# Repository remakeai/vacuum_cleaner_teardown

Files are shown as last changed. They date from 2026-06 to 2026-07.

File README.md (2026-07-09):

# vacuum_cleaner_teardown
A home vacuum robot cleaner teardown

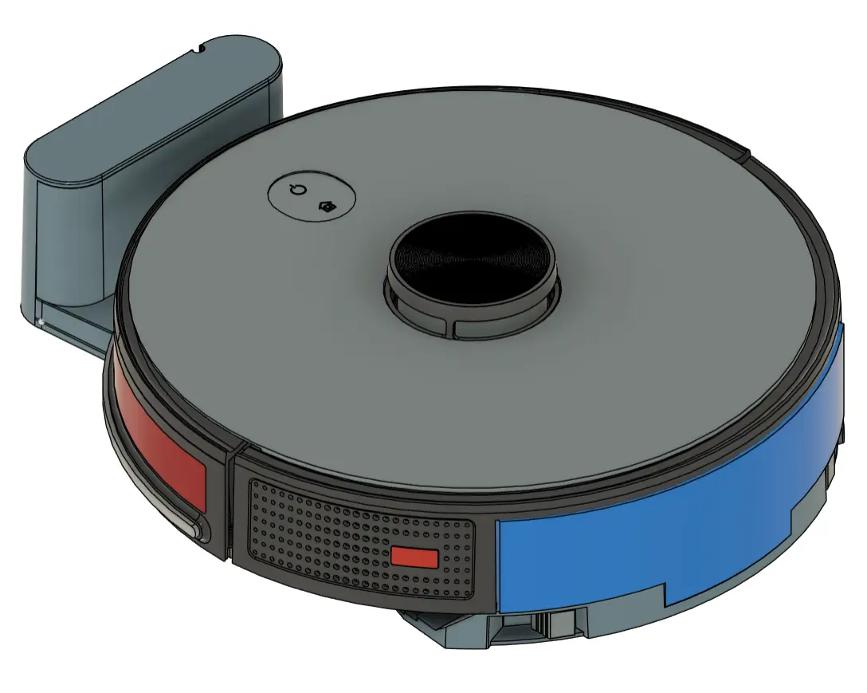
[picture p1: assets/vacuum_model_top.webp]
Vacuum cleaner 3D model top view


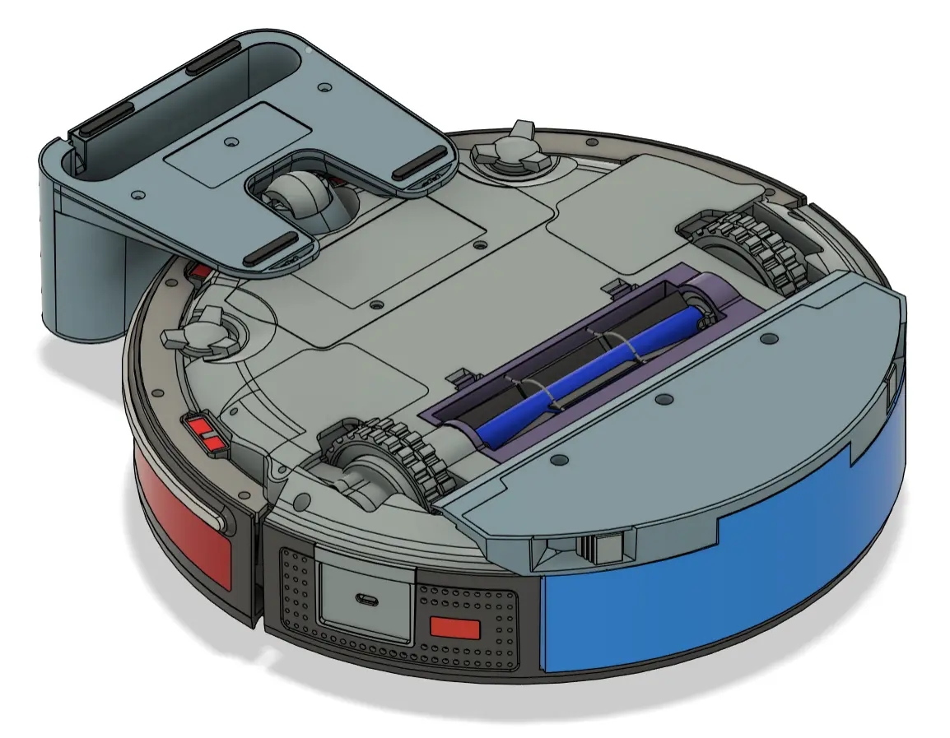
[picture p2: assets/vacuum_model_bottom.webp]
Vacuum cleaner 3D model bottom view


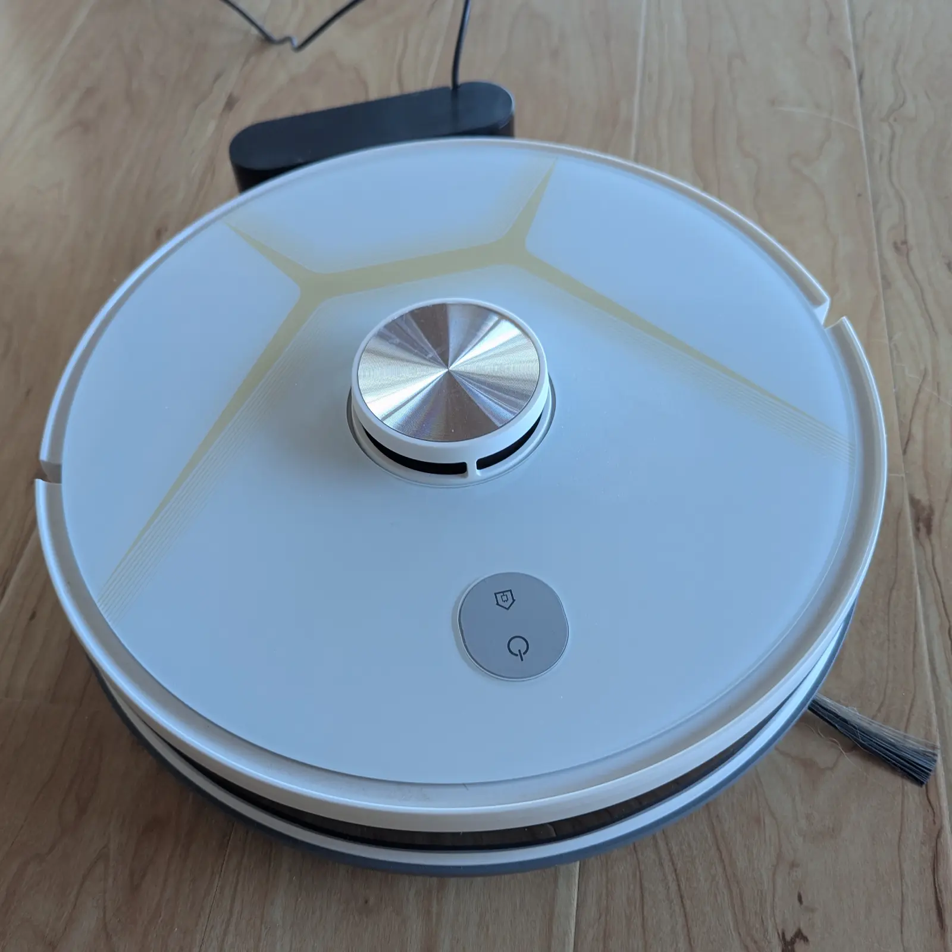
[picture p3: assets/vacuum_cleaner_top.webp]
Vacuum cleaner photo


## PCB

| Device | Model |
| --- | --- |
| Allwinner F1C200s | 64MB in-package RAM |
| BoyaMicro 25Q128ESS1G |  |
| Wheel motor driver | A4950T |
| Wheel motor | 365SA1887 DC 7.4V w/encoder |
| Battery | 3S 2600mAh |
| MCU | Artery AT32F403AVGT7 |
| WiFi | SV6355 2.4GHz WiFi BLE 5.0 module |
| Side brush motors | RF-500C-13430 DV 7.4V |
| Suction fan | EBO Innovation EBO-A65126 DC 8.4V 1.4A, DC 12.6V 2.2A |
| Speaker | 8 Ohm |
| Audio amp | 8002D1 |

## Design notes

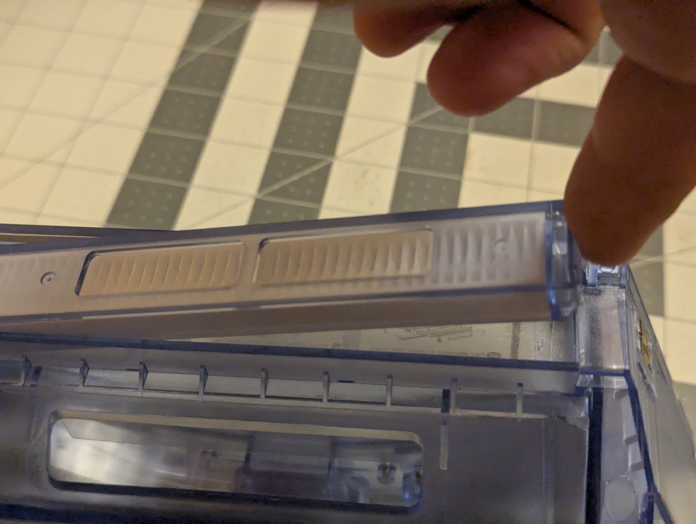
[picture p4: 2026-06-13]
assets/dust_bin/dust_bin_11.jpg

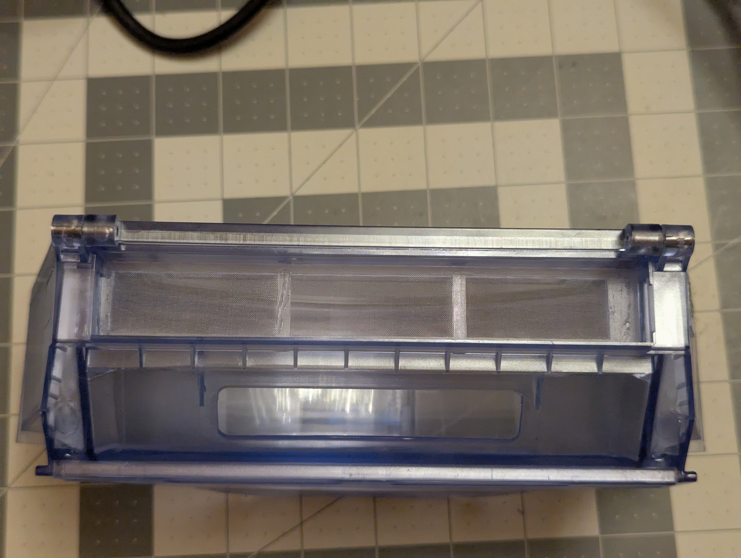
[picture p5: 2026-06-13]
assets/dust_bin/dust_bin_14.jpg

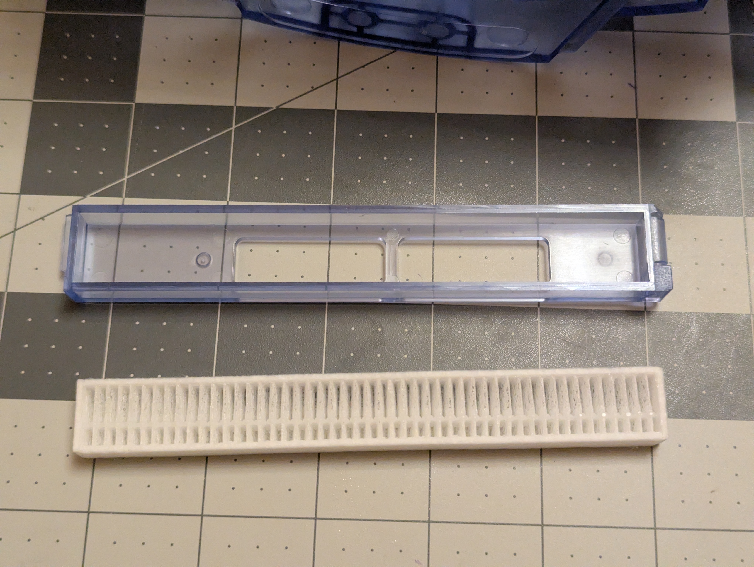
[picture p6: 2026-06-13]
assets/dust_bin/dust_bin_13.jpg

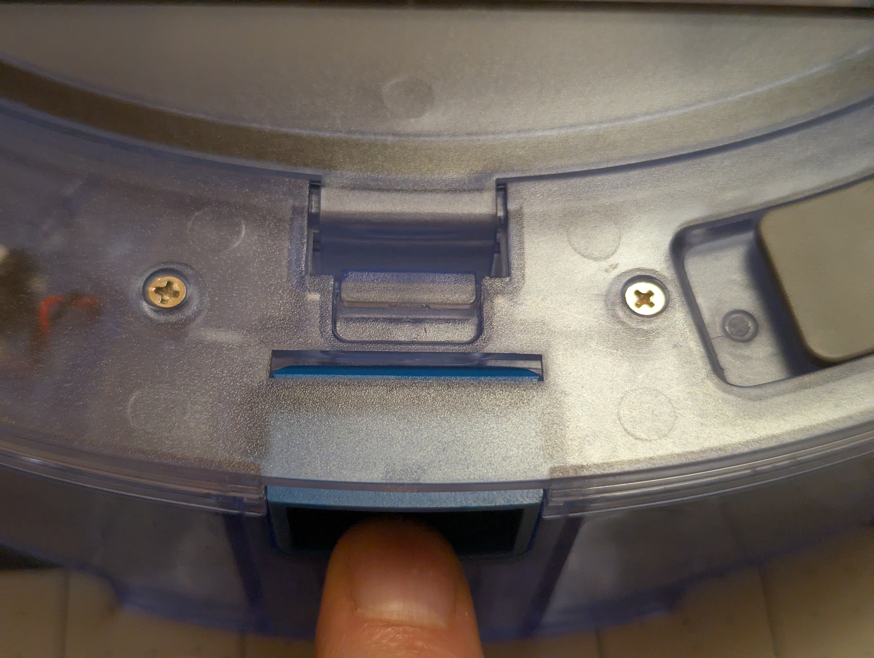
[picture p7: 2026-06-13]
assets/dust_bin/dust_bin_10.jpg

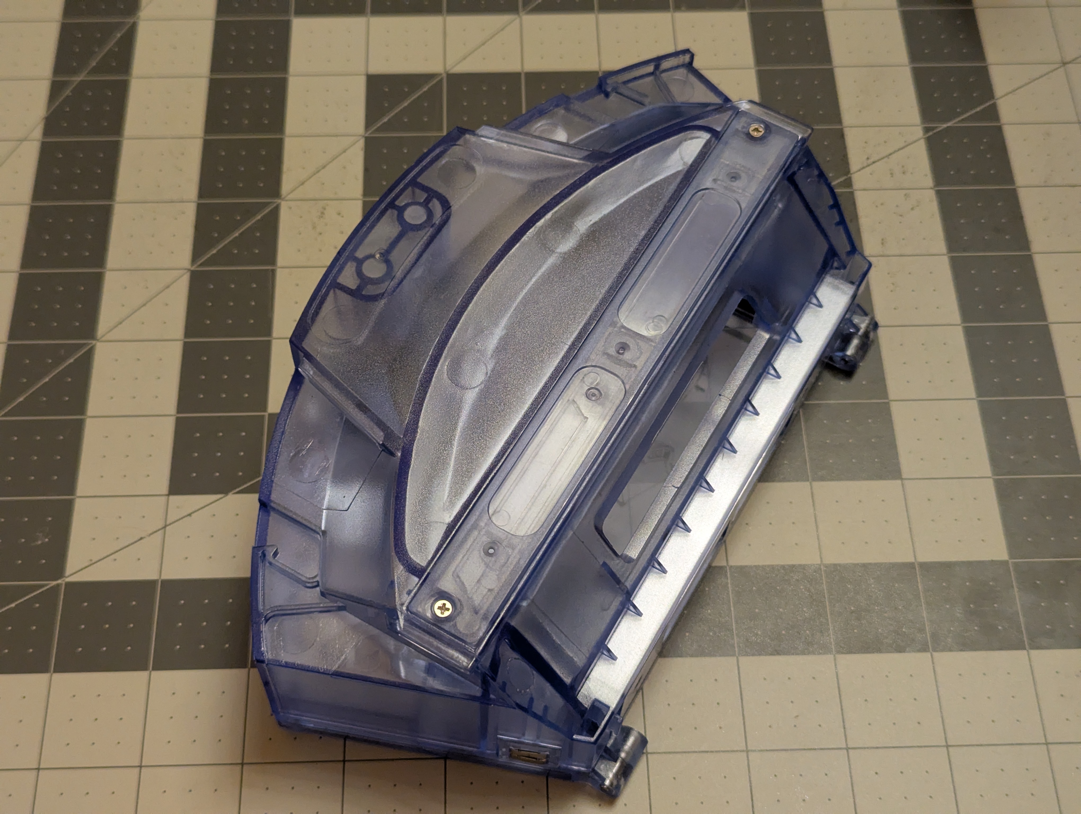
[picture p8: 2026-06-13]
assets/dust_bin/dust_bin_4.jpg

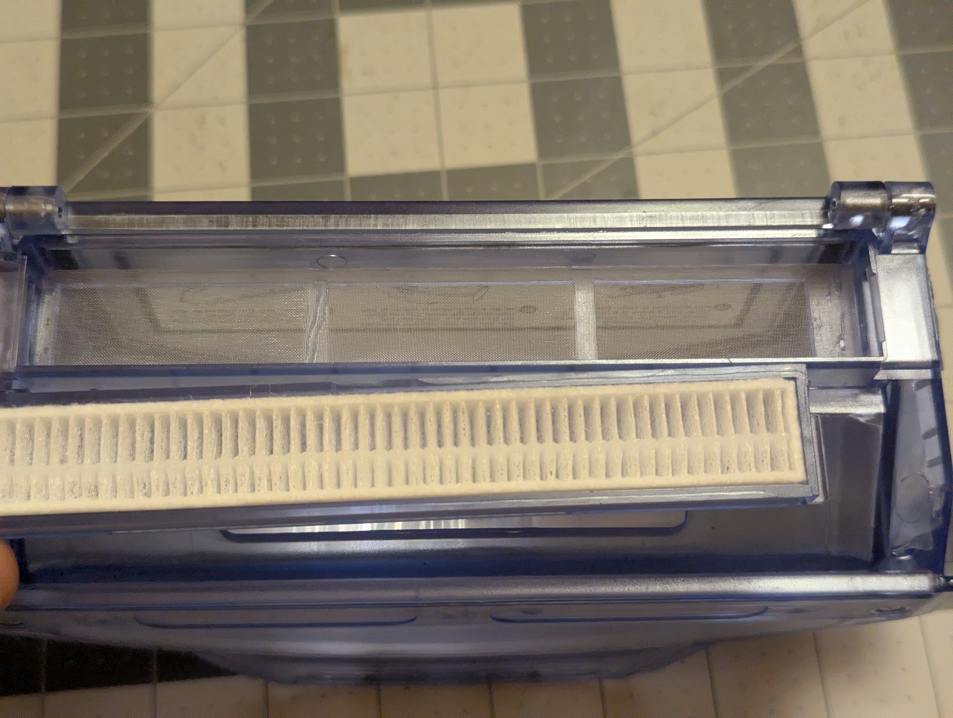
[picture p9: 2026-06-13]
assets/dust_bin/dust_bin_12.jpg

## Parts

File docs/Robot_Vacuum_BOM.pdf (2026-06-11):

Group | Part ID | PHOTO | Part Name | Type | Notes | STATUS
Chassis | C01 | | Main Chassis (Bottom Case) | PRT | Main plastic body frame. | SUBASSEMBLED
Chassis | C02 | | Main Chassis top cover | PRT | Circular top cover. | ASSEMBLED
Chassis | C03 | | Main Chassis Middle Frame | ASM | | ASSEMBLED
Chassis | C03-01 | | Inner Frame | PRT | Internal structural support. | SUBASSEMBLED
Chassis | C03-02 | | IR window | PRT | Mini IR Window 2pcs | SUBASSEMBLED

Chassis | 04-01 | Bumper Frame | PRT | Dark transparent plastic. | SUBASSEMBLED
Chassis | C04-02 | Bumper Lower Trim | PRT | Rubber guard/seal for bumper bottom. | SUBASSEMBLED
Chassis | C04-03 | Bumper IR Window | PRT | Dark transparent curved plastic. | SUBASSEMBLED
Chassis | C04 | Front Bumper | ASM | | ASSEMBLED
Chassis | C05-01 | Wall Sensor Housing | PRT | Black plastic sensor enclosure. *4pcs | SUBASSEMBLED
Chassis | C05-02 | Wall Sensor IR Window | PRT | Black plastic sensor window. *4pcs | SUBASSEMBLED

Chassis | C05-03 | Wall Sensor Board | PRT | Sensor board. *4pcs | SUBASSEMBLED
Chassis | C05 | SUBASSEMBLY | ASM | | ASSEMBLED
Chassis | C06 | Battery compartment cover | PRT | Cover with model label. | ASSEMBLED
Chassis | C07 | Type-C Port sub assembly | assm | | ASSEMBLED
Chassis | C07-01 | Type-C Port Cover | PRT | Charging port plastic housing. | SUBASSEMBLED
Chassis | C07-02 | Type-C Port Board | PRT | Charging port board. | SUBASSEMBLED

Chassis | C08 | LIDAR Top Cap | PRT | Cosmetic cover for laser. | ASSEMBLED
Chassis | C09 | Bumper Frame | PRT | External shock absorber. | ASSEMBLED
Mechanics | M01L | Drive Wheel Module (L) | ASM | MIRROR OF RIGHT | ASSEMBLED
Mechanics | M01R-01 | Right Wheel Gearbox Housing | PRT | Plastic gear housing. | ASSEMBLED
Mechanics | M01R-02 | Right Wheel DC Motor | PRT | Brushed DC motor with pinion. | ASSEMBLED
Mechanics | M01R-03 | Right Wheel Gearbox Cover | PRT | Plastic cover for gears. | SCANNED

Mechanics | M01-04 | Steel pin of gearbox | PRT | Steel pin for hinge. | ASSEMBLED
Mechanics | M01R | Drive Wheel Module (R) | ASM | DC motor + gearbox + tire. | ASSEMBLED
Mechanics | M02 | Front Caster Housing | PRT | Swivel housing. | ASSEMBLED
Mechanics | M03 | Front Caster Roller | PRT | Black/White roller ball. | ASSEMBLED
Mechanics | M04-01 | Blower Motor & Impeller | ASM | EBO DC motor assembly. | SUBASSEMBLED
Mechanics | M04-02-01 | Blower Housing (Volute) | PRT | Plastic casing for vacuum fan. | SUBASSEMBLED

Mechanics | M04-02-02 | Blower Housing (Volute) | PRT | Plastic casing for vacuum fan. | SUBASSEMBLED
Mechanics | M04-02 | Blower Housing (Volute) | ASM | SUBASSEMBLY | SUBASSEMBLED
Mechanics | M04-03 | Blower Exhaust Gasket | PRT | Rubber vibration/seal pad. | SUBASSEMBLED
Mechanics | M04-04 | Rubber Pins | PRT | Blower Housing Rubber pins. | SUBASSEMBLED
Mechanics | M04 | Vacuum Fan (EBO) | ASM | Centrifugal fan blower. | ASSEMBLED
Mechanics | M05 | Main Roller Brush Motor Box | ASM | Geared motor assembly. | ASSEMBLED

Mechanics | M05-01 | Main Roller Brush Gearbox | PRT | Gear reduction housing. | ASSEMBLED
Mechanics | M05-02 | Main Roller Brush DC Motor | PRT | Brushed motor with worm gear. | ASSEMBLED
Mechanics | M06R | Side Brush DC Motor | ASM | | ASSEMBLED
Mechanics | M06R-01 | Side Brush DC Motor | PRT | | SUBASSEMBLED
Mechanics | M06-2 | Side Brush DC Motor | PRT | | SUBASSEMBLED
Mechanics | M06L | Side Brush DC Motor | ASM | | ASSEMBLED

Mechanics | M06L-01 | Side Brush DC Motor | PRT | | SUBASSEMBLED
Electronics | E01-01 | Mainboard PCBA | ASM | Central processing unit. | SUBASSEMBLED
Electronics | E01-02 | Board Holder Bracket | PRT | Black plastic support bracket. | SUBASSEMBLED
Electronics | E01 | Mainboard PCBA with Holder | PRT | | ASSEMBLED
Electronics | E02 | Li-ion Battery Pack | ASM | Blue shrink wrap, 2600mAh. | ASSEMBLED
Electronics | E03 | LIDAR Module | ASM | Laser Distance Sensor unit. | ASSEMBLED

Electronics | E04 | UI Button Module | ASM | Power/Home interface PCB. | ASSEMBLED
Electronics | E04-01 | UI Button | PRT | Power/Home interface PCB. | SUBASSEMBLED
Electronics | E04-02 | UI Button Plastics | PRT | left and right | SUBASSEMBLED
Electronics | E04-03 | UI Button Plastics | PRT | left and right | SUBASSEMBLED
Electronics | E05R | Edge/Cliff Sensor PCB | ASM | Green sensor boards. | ASSEMBLED
Electronics | E05L | Edge/Cliff Sensor PCB | ASM | Green sensor boards. | ASSEMBLED

Electronics | E06 | Speaker Unit | ASM | Audio output speaker. | ASSEMBLED
Electronics | E07-01 | Dock Top Housing | PRT | Upper plastic shell of the dock. | SUBASSEMBLED
Electronics | E07-02 | Dock IR Window | PRT | Dark red transparent cover. | SUBASSEMBLED
Electronics | E07-03 | Dock Bottom Housing | PRT | | SUBASSEMBLED
Electronics | E07-04 | Dock Mainboard PCBA | PRT | Circuit board with IR emitters. | SUBASSEMBLED
Electronics | E07-05 | Dock Charging Plate | PRT | Circuit board with IR emitters. | SUBASSEMBLED

Electronics | E07 | Charging Dock Station | ASM | External power base station. | ASSEMBLED
User/Shell | U01 | Hybrid Dust/Water Tank | ASM | 2-in-1 container. | ASSEMBLED
User/Shell | U02 | Main Roller Brush Cover with lip | PRT | HEPA filter holder. | ASSEMBLED
User/Shell | U03 | Main Roller Brush | PRT | Blue bristled brush.*2pcs | ASSEMBLED
User/Shell | U04 | Side brush | PRT | 2 pcs | ASSEMBLED
User/Shell | U05-01 | Mop Housing Bottom | PRT | | SUBASSEMBLED

User/Shell | U05-02 | Mop Housing Top | PRT | | SUBASSEMBLED
User/Shell | U05-03 | Spring | PRT | | SUBASSEMBLED
User/Shell | U05-04 | Spring Loaded Button | PRT | | SUBASSEMBLED
User/Shell | U05-05 | Spring Loaded Button | PRT | | SUBASSEMBLED
User/Shell | U05 | Mop Attachment Bracket | PRT | | SUBASSEMBLED
Hardware | H01 | Metal Cable Plates | PRT | 2 pcs | ASSEMBLED

Hardware | H02 | Leaf Spring Contact | PRT | | ASSEMBLED
Hardware | H03 | Extension Springs | PRT | *2 pcs | ASSEMBLED
Hardware | H04 | Torsion Spring Pair | PRT | *2 pcs | ASSEMBLED
Hardware | H05R | Front bumper strut | PRT | *2 pcs | ASSEMBLED
Hardware | H05L | | PRT | *2 pcs | ASSEMBLED
Hardware | H06 | | PRT | | IMAGED

Front bumper strut

Hardware | H07 | Screw Set B (White) | PRT | IMAGED
Hardware | H09 | Front Caster pin | PRT | ASSEMBLED
Hardware | H10 | 688Z BEARING | PRT | ASSEMBLED

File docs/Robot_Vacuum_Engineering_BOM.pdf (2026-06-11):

## Robot Vacuum - Engineering BOM

Reverse Engineering Documentation

February 14, 2026

## Classification Legend

- Project Code:
- Group Codes (Mnemonic):

– C: Chassis - Structural Base

– M: Mechanics - Moving Parts

– E: Electronics - Brain & Power

– U: User/Shell - External Housing

– H: Hardware - Fasteners & Springs

- ASM (Assembly): Sub-assembly containing multiple parts.
- PRT (Part): Single, non-demountable component.

## 1 Group C: Chassis (Structural Skeleton)

The foundation: Internal frames, housings, and fixed plastic parts.

Image | Part ID | Part Name | Type | Notes
| C01 | Main Case) Chassis (Bottom | PRT | Main plastic body frame.
| C02 | Base Plate (Disk) | PRT | Circular bottom cover.

Image | Part ID | Part Name | Type | Notes
| C03-01 | Inner Frame | PRT | Internal structural sup-port.
| C03-02 | IR window | PRT | Mini IR Window 2pcs
| C04 | Board Holder Bracket | PRT | Black plastic support bracket.
| C05-01 | Wall Sensor Housing | PRT | Black plastic sensor en-closure. *4pcs
| C05-02 | Wall Sensor IR Window | PRT | Black plastic sensor window. *4pcs
| C05-03 | Wall Sensor Board | PRT | Sensor board. *4pcs
| C06 | Battery/Service Door | PRT | Cover with model label.
| C07-01 | Type-C Port Cover | PRT | Charging port plastic housing.

Image | Part ID | Part Name | Type | Notes
| C07-02 | Type-C Port Board | PRT | Charging port board.
| C08 | LIDAR Top Cap | PRT | Cosmetic cover for laser (Moved from Shell).
| C09 | Bumper Frame | PRT | External shock ab-sorber.
| C10-01 | Bumper IR Window | PRT | Dark transparent plas-tic.
| C10-02 | Bumper Lower Trim | PRT | Rubber guard/seal for bumper bottom.
| C10-03 | Bumper IR Window | PRT | Dark transparent curved plastic.

## 2 Group M: Mechanics (Actuation & Muscles)

Image | Part ID | Part Name | Type | Notes
| M01L | Drive Wheel Module (L/R) | ASM | DC motor + gearbox + tire.

Image | Part ID | Part Name | Type | Notes
| M01R | Drive Wheel Module (L/R) | ASM | DC motor + gearbox + tire.
| M01R-01 | Right Wheel Gearbox Housing | PRT | Plastic gear housing.
| 02 M01R- | Right Wheel DC Motor | PRT | Brushed DC motor with pinion.
| M01R-03 | Right Wheel Gearbox Cover | PRT | Plastic cover for gears.
| M01R-04 | Steel pin of gearbox | PRT | Steel pin for hinge.
| M02 | Front Caster Housing | PRT | Swivel housing.
| M03 | Front Caster Roller | PRT | Black/White roller ball.
| M04 | Vacuum Fan (EBO) | ASM | Centrifugal fan blower.

Image | Part ID | Part Name | Type | Notes
| M04-01 | Blower Motor & Impeller | ASM | EBO DC motor assem-bly.
| M04-02 | Blower Housing (Volute) | PRT | Plastic casing for vac-uum fan.
| M04-03 | Blower Exhaust Gasket | PRT | Rubber vibration/seal pad.
| M04-04 | Rubber Pins | PRT | Blower Housing Rubber pins.
| M05 | Side Brush Motor Box | ASM | Geared motor assembly.
| M05-01 | Side Brush Gearbox | PRT | Gear reduction housing.
| M05-02 | Side Brush DC Motor | PRT | Brushed motor with worm gear.
| M06L | Secondary Actuator | ASM | Small DC motor unit.
| M06R | Secondary Actuator | ASM | Small DC motor unit.

Image | Part ID | Part Name | Type | Notes
| 01 M06R- | Actuator Gearbox Housing | PRT | Right side small gear housing.
| 02 M06R- | Actuator DC Motor | PRT | Small brushed motor with pinion.

## 3 Group E: Electronics (Brain, Sensors & Power)

Image | Part ID | Part Name | Type | Notes
| E01 | Mainboard PCBA | ASM | Central processing unit.
| E02 | Li-ion Battery Pack | ASM | Blue shrink wrap, 2600mAh.
| E03 | LIDAR Module | ASM | Laser Distance Sensor unit.
| E04 | UI Button Module | ASM | Power/Home interface PCB.
| E05 | Edge/Cliff Sensor PCB | ASM | Green sensor boards.

Image | Part ID | Part Name | Type | Notes
| E06 | Speaker Unit | ASM | Audio output speaker.
| E07 | Charging Dock Station | ASM | External power base station.
| E07-01 | Dock Top Housing | PRT | Upper plastic shell of the dock.
| E07-02 | Dock IR Window | PRT | Dark red transparent cover for IR alignment.
| E07-03 | Dock Base Housing | PRT | Lower plastic base with mounting points.
| E07-04 | Dock Mainboard PCBA | ASM | Circuit board with IR emitters.
| E07-05 | Dock Charging Contacts | PRT | Metal spring plates with wire leads.

## 4 Group U: User/Shell (External & Consumables)

Image | Part ID | Part Name | Type | Notes
| U01 | Hybrid Dust/Water Tank | ASM | 2-in-1 container.
| U02 | Filter Frame | PRT | HEPA filter holder.
| U03 | Main Roller Brush | PRT | Blue bristled brush.*2pcs
| U04 | Side Brush Pair | PRT | 3-arm sweeping brushes.
| U05 | Mop Attachment Bracket | PRT | Base plate for mopping cloth.

## 5 Group H: Hardware (Springs, Fasteners & Misc)

Image | Part ID | Part Name | Type | Notes
| H01 | Metal Cable Plates | PRT | Shielding/retention plates.
| H02 | Leaf Spring Contact | PRT | Bended metal plate.

Image | Part ID | Part Name | Type | Notes
| H03 | Extension Springs | PRT | Wheel suspension springs.
| H04 | Torsion Spring Pair | PRT | Mechanism springs.
| H05 | Locking Latches | PRT | Black plastic retention hooks.
| H06 | Screw Set A (Yellow) | PRT | Mixed assembly screws.
| H07 | Screw Set B (White) | PRT | Additional fasteners.
| H08L | UI Button Plastics | PRT | Left Button.
| H08R | UI Button Plastics | PRT | Right Button.
| H09 | Steel Pivot Pin | PRT | Metal shaft.

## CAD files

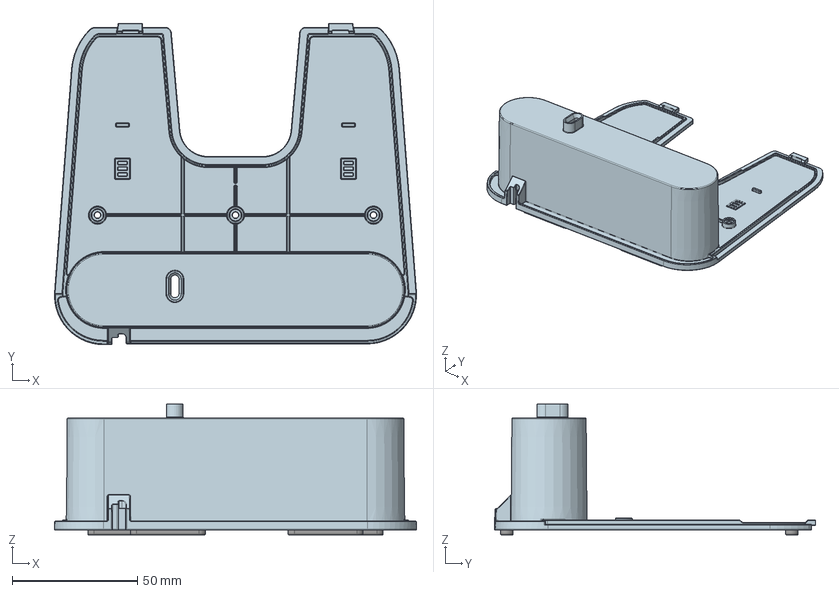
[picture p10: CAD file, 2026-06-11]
step/E07-03.stp
144.6 x 128.3 x 52.3 mm

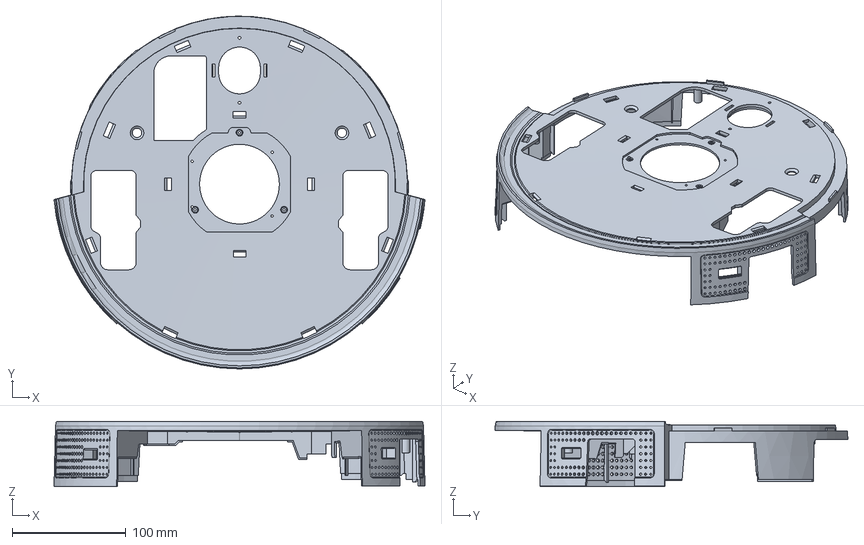
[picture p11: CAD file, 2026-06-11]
step/C03-01.stp
325.8 x 309.9 x 57.2 mm

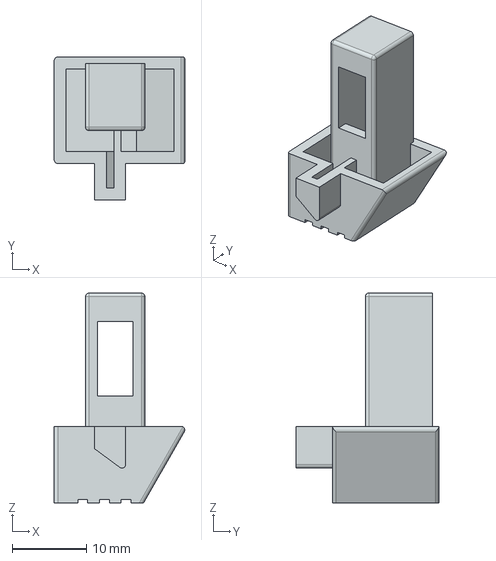
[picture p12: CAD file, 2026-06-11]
step/U05-5.stp
17.5 x 19.2 x 28.2 mm

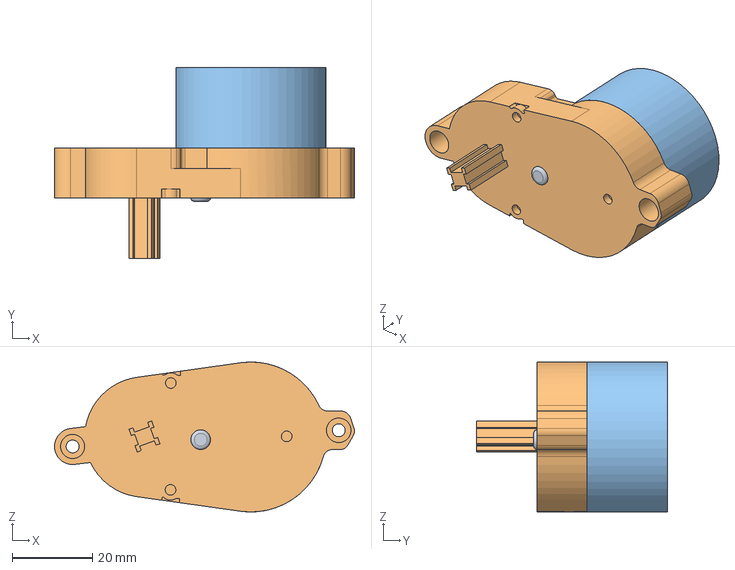
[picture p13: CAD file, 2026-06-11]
step/M06R-01.stp
74.6 x 47.4 x 37.3 mm

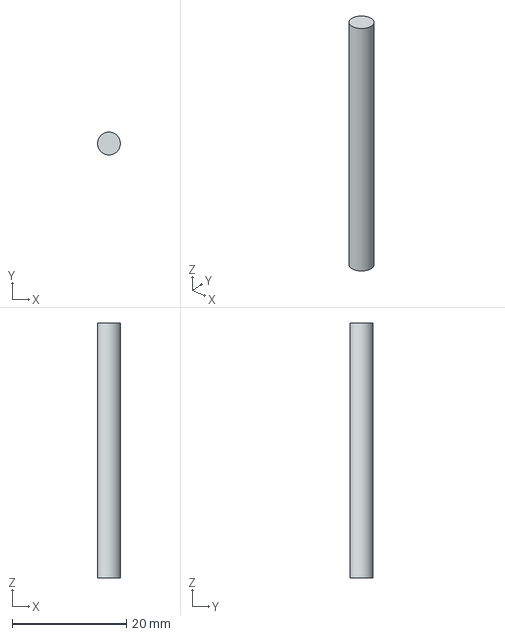
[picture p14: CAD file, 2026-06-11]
step/M01R-04.stp
4.00 x 4.00 x 44.7 mm

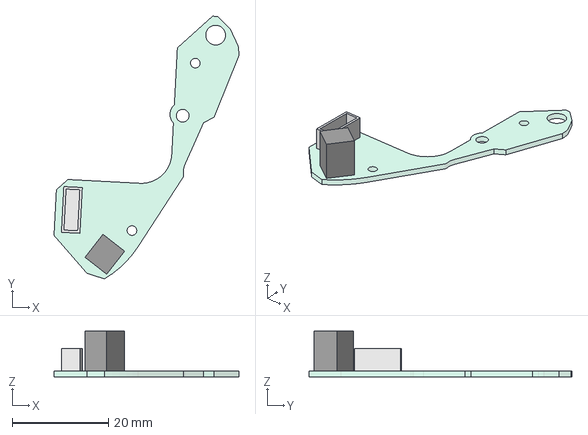
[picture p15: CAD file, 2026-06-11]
step/E05L.stp
38.3 x 54.5 x 9.45 mm

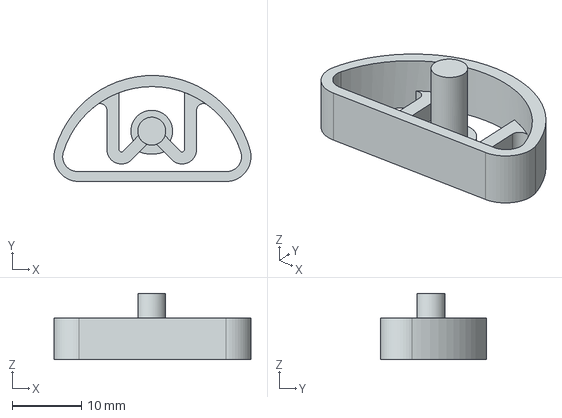
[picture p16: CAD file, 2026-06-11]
step/E04-02.stp
28.5 x 15.4 x 9.60 mm

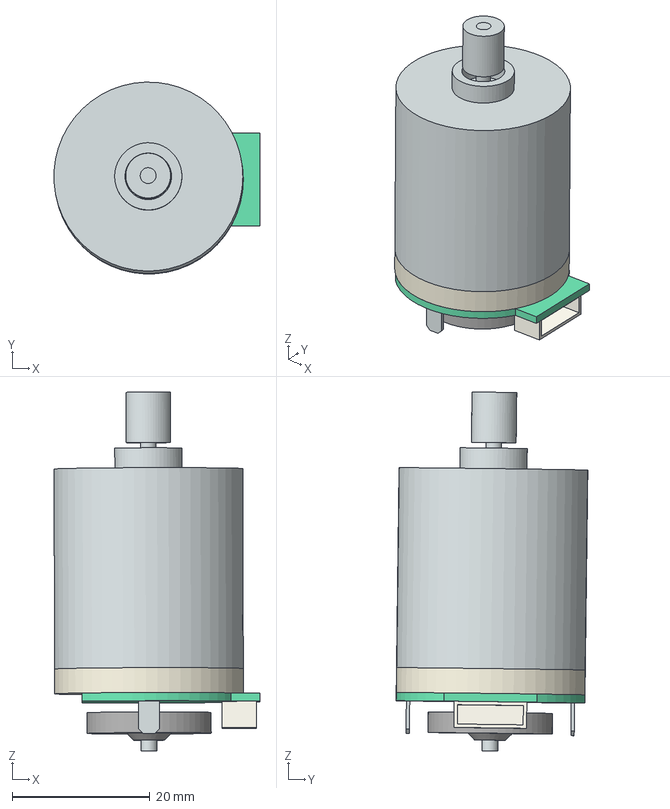
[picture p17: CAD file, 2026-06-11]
step/M01L-02.stp
29.9 x 27.8 x 52.1 mm

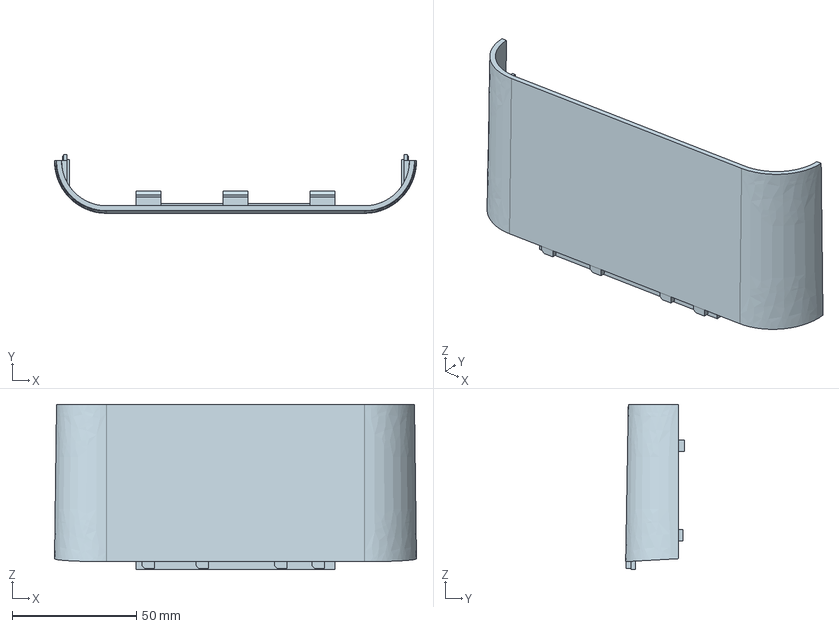
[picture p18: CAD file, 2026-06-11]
step/E07-02.stp
145.7 x 23.6 x 66.5 mm

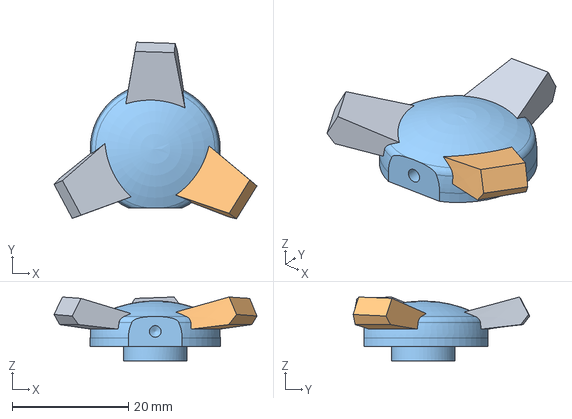
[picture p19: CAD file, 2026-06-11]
step/U04.stp
35.0 x 30.4 x 11.0 mm

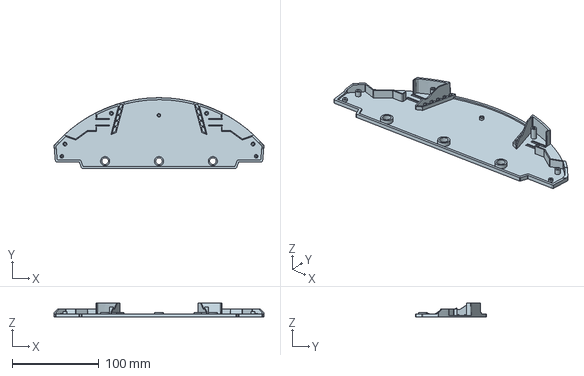
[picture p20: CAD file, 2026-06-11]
step/U05-2.stp
241.8 x 81.4 x 16.2 mm

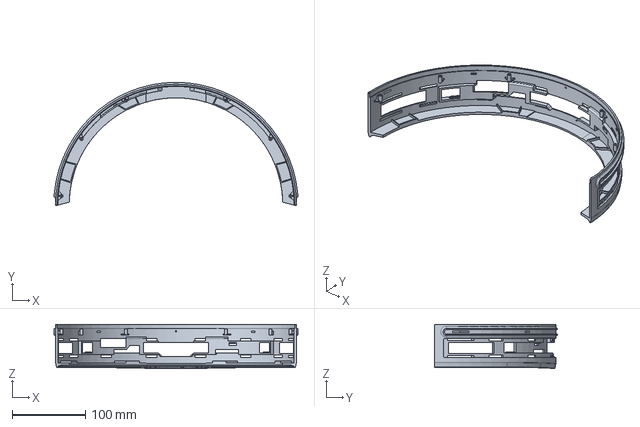
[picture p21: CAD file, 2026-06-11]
step/C04-1.stp
332.3 x 168.0 x 60.1 mm

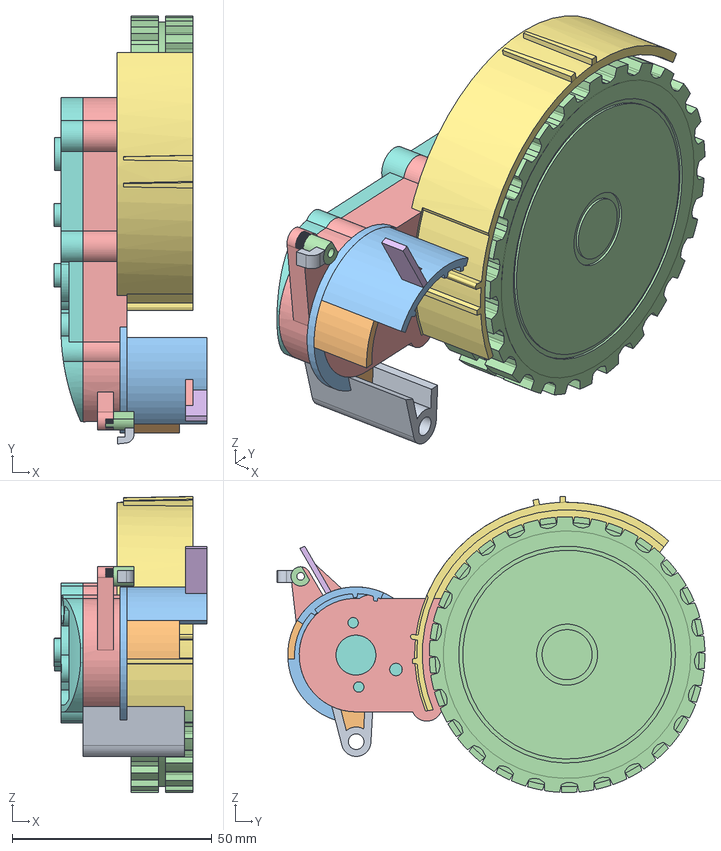
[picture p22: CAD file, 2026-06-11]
step/M01R-01.stp
38.3 x 107.2 x 74.2 mm

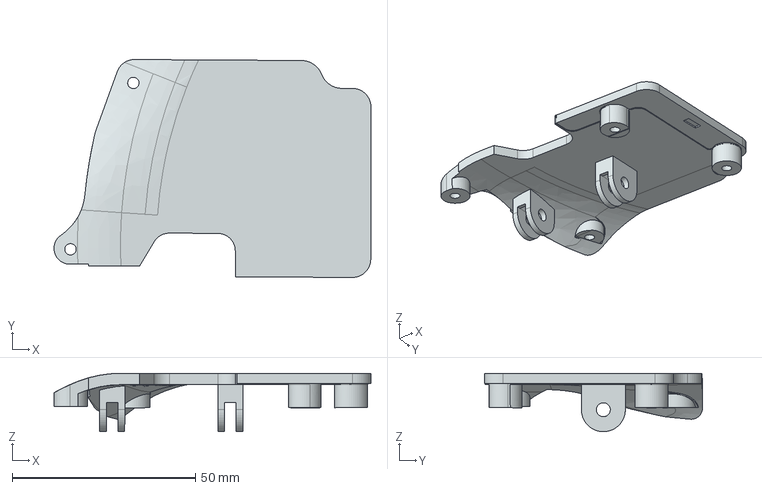
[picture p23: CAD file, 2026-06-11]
step/M01R-03.stp
86.6 x 59.5 x 16.0 mm

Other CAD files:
step/U05-4.stp
step/Traceline_Curves.stp
step/C06.stp
step/H04R.stp
step/C01.stp
step/C02.stp
step/C03-02.stp
step/C04-2.stp
step/C04-3.stp
step/C05-01.stp
step/C05-02.stp
step/C05-03.stp
step/C07-01.stp
step/C07-02.stp
step/C08.stp
step/C09.stp
step/E01-01.stp
step/E01-02.stp
step/E02.stp
step/E03.stp
step/E04-01.stp
step/E04-03.stp
step/E05R.stp
step/E06.stp
step/E07-01.stp
step/E07-04.stp
step/E07-05.stp
step/H01.stp
step/H02.stp
step/H03.stp
step/H04L.stp
step/H05.stp
step/H09.stp
step/H10.stp
step/M01L-01.stp
step/M01L-03.stp
step/M01L-04.stp
step/M01R-02.stp
step/M02.stp
step/M03.stp
step/M04-01.stp
step/M04-02-01.stp
step/M04-02-02.stp
step/M04-03.stp
step/M04-04.stp
step/M05-01.stp
step/M05-02.stp
step/M06-02.stp
step/M06L-01.stp
step/MASTER-ASSM.stp
step/U01.stp
step/U02.stp
step/U03.stp
step/U05-1.stp
step/U05-3.stp

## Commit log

2026-06-11 STEP files
    [C01.stp, C02.stp, C03-01.stp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]
2026-07-09 Update README with PCB details and image
    Added PCB specifications and a new vacuum cleaner photo.
